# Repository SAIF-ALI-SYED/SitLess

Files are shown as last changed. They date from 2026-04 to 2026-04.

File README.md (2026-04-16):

# SitLess

**An AI-Driven Sedentary Monitoring System with a 3-DOF Robotic Arm**

SitLess is an AIoT system that detects prolonged sitting using an ESP32 microcontroller, ultrasonic sensor, and a trained Random Forest classifier. When sitting is detected for too long, alerts escalate — from a buzzer beep (30s) to a physical robotic arm tap (60s). A Streamlit dashboard provides real-time monitoring and manual controls.

> Built as a second-year individual project.

---

<p align="center">
  SitLess Demo
</p>

<p align="center">
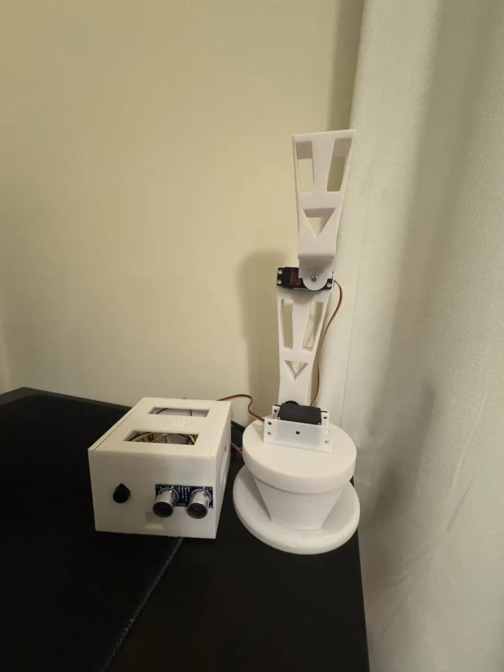
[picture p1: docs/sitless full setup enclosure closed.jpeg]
Full Setup
  
  &nbsp;&nbsp;
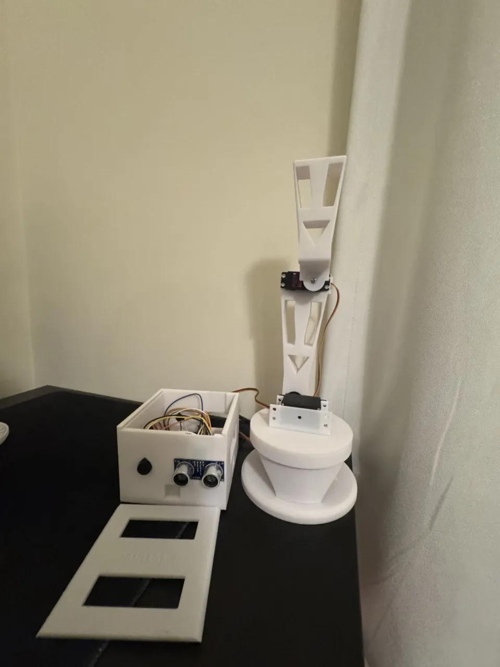
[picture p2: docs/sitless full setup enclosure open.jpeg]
Inside View
  
  &nbsp;&nbsp;
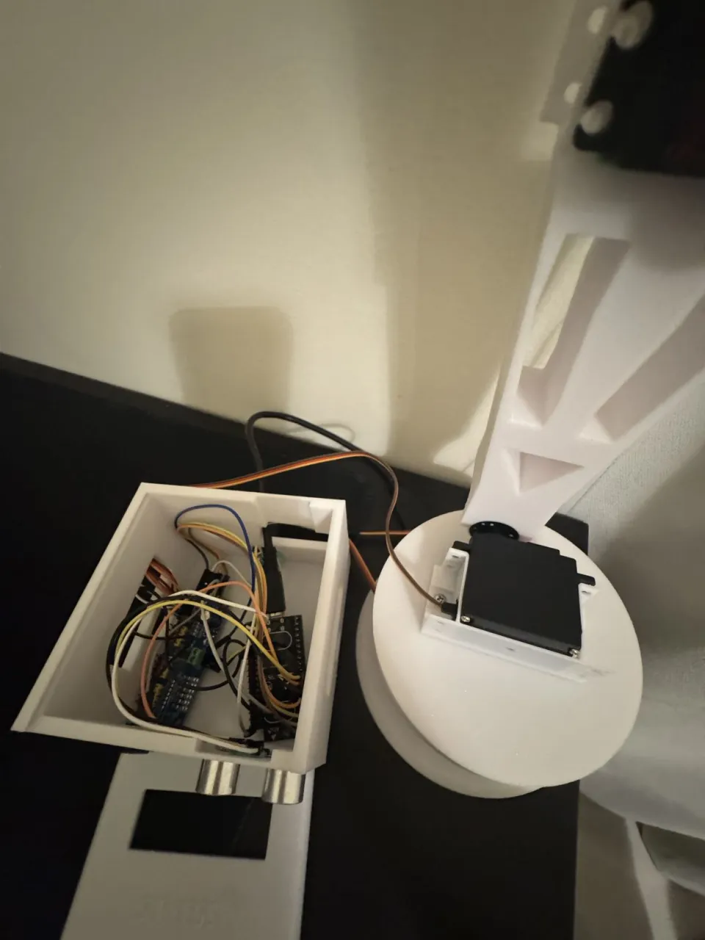
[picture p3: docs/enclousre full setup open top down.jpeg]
Top-Down
  
</p>

---

## How It Works

```
HC-SR04 Sensor → ESP32 → Serial → Python Backend → Random Forest → Alert System
                                                                    ├── Buzzer (30s)
                                                                    └── Robotic Arm Tap (60s)
```

1. The **ESP32** reads ultrasonic distance every 200ms and sends it over serial
2. The **Python backend** collects readings into sliding windows (10 samples, step 5) and extracts features
3. A **Random Forest classifier** predicts the activity state: `active`, `sedentary`, or `not present`
4. If sedentary for too long, **escalating alerts** trigger — first a buzzer beep, then a physical tap from the 3-DOF arm
5. A **Streamlit dashboard** shows real-time state, distance, inactivity timer, and provides manual controls

---

## Machine Learning

| Detail | Value |
|---|---|
| Model | Random Forest (100 estimators) |
| Test Accuracy | **85.1%** |
| Dataset | 1,473 samples → 234 feature windows |
| Window Size | 10 samples (step 5) ≈ 2 seconds |
| Classes | Active, Sedentary, Not Present |

### Features Extracted Per Window

| Feature | Description | Importance |
|---|---|---|
| `rate_of_change` | Mean absolute difference between consecutive readings | **34.5%** |
| `std_distance` | Standard deviation of distances | **26.8%** |
| `range_distance` | Max − Min distance in window | **22.6%** |
| `mean_distance` | Average distance | 16.1% |

The top features (rate of change and standard deviation) capture **movement variability** — the key signal distinguishing active vs sedentary behaviour.

---

## Hardware

| Component | Purpose |
|---|---|
| ESP-32D | Microcontroller |
| HC-SR04 | Ultrasonic distance sensor |
| PCA9685 | 16-channel PWM servo driver |
| 3× MG996R | Servo motors (base, shoulder, elbow) |
| Piezo buzzer | Audio alert |
| 5V 3A DC supply | Power |
| 3D-printed PLA enclosure | Housing (FreeCAD files included) |

**Total hardware cost: approximately 200 AED (~$55 USD)**

---

## Repository Structure

```
SitLess/
├── Sitless_Final_Arduino_Code.ino   # ESP32 firmware (Arduino IDE)
├── Python & CSV & Graphs/
│   ├── live_prediction.ipynb        # ML backend — serial + prediction + alerts
│   ├── dashboard.py                 # Streamlit web dashboard
│   ├── data_collection.ipynb        # Raw data collection from sensor
│   ├── data_cleaning.ipynb          # Cleaning & preprocessing
│   ├── extract_features.ipynb       # Sliding window feature extraction
│   ├── model_training.ipynb         # Model training & evaluation
│   ├── *.csv                        # Datasets (raw + processed)
│   └── *.png                        # Output charts & visualisations
├── FreeCAD files/                   # CAD files for enclosure & robotic arm
└── README.md
```

---

## Getting Started

### Prerequisites

- Python 3.8+
- Arduino IDE
- ESP32 board package installed in Arduino IDE

### Install Dependencies

```bash
pip install pyserial pandas numpy scikit-learn joblib streamlit matplotlib
```

### 1. Flash the ESP32

Open `Sitless_Final_Arduino_Code.ino` in Arduino IDE and upload to your ESP32 (connected on COM4 by default).

### 2. Start the ML Backend

```bash
# Open Jupyter and run:
jupyter notebook "Python & CSV & Graphs/live_prediction.ipynb"
```

### 3. Launch the Dashboard

```bash
# In a separate terminal:
streamlit run "Python & CSV & Graphs/dashboard.py"
```

The backend and dashboard communicate via shared JSON files (`state.json` and `commands.json`).

---

## Alert Escalation Logic

```
Sedentary detected → Timer starts
                     ├── 0–30s:  Monitoring (no alert)
                     ├── 30s:    Buzzer beep
                     └── 60s:    Robotic arm tap
                     
Active for 5s → Timer resets
```

---

## Custom 3-DOF Robotic Arm

The robotic arm was designed from scratch in FreeCAD and 3D-printed in PLA. It has three degrees of freedom — base rotation, shoulder lift, and elbow extension — driven by three MG996R servo motors through a PCA9685 PWM driver.

The arm's tap motion was tuned manually using incremental stepping to find reliable angles:

| Joint | Rest Position | Tap Position |
|---|---|---|
| Base | 180° | 40° |
| Shoulder | 90° | 150° |
| Elbow | 90° | 40° |

On a tap command, the servos move sequentially — base rotates, shoulder raises, elbow extends — then retract in reverse order. The motion is deliberate enough to get your attention without being aggressive.

The `FreeCAD files/` folder contains all the CAD models for both the arm and the sensor enclosure (which holds the HC-SR04 at the front with the ESP32 mounted inside).

---

## Future Improvements

- Multi-user data collection for better generalisation
- Bluetooth/Wi-Fi to replace USB serial
- Inverse kinematics to replace the current predefined angle movements with dynamic positioning
- Historical data logging and wellness trend tracking
- Additional sensors (PIR, second ultrasonic) for better accuracy
- On-device inference for privacy

---

## Built With

- **Hardware:** ESP32, HC-SR04, PCA9685, MG996R servos
- **ML:** scikit-learn (Random Forest), pandas, NumPy
- **Dashboard:** Streamlit
- **CAD:** FreeCAD
- **Firmware:** Arduino (C++)

---

## License

This project was developed for academic purposes. Feel free to use it as reference or inspiration for your own projects.

---

## Author

**Saif Ali Syed** — BEng (Honours) Computer Systems Engineering, Middlesex University Dubai  
[LinkedIn](https://www.linkedin.com/in/saif-ali-syed-a87aa534a/) <!-- Replace with your actual LinkedIn URL -->

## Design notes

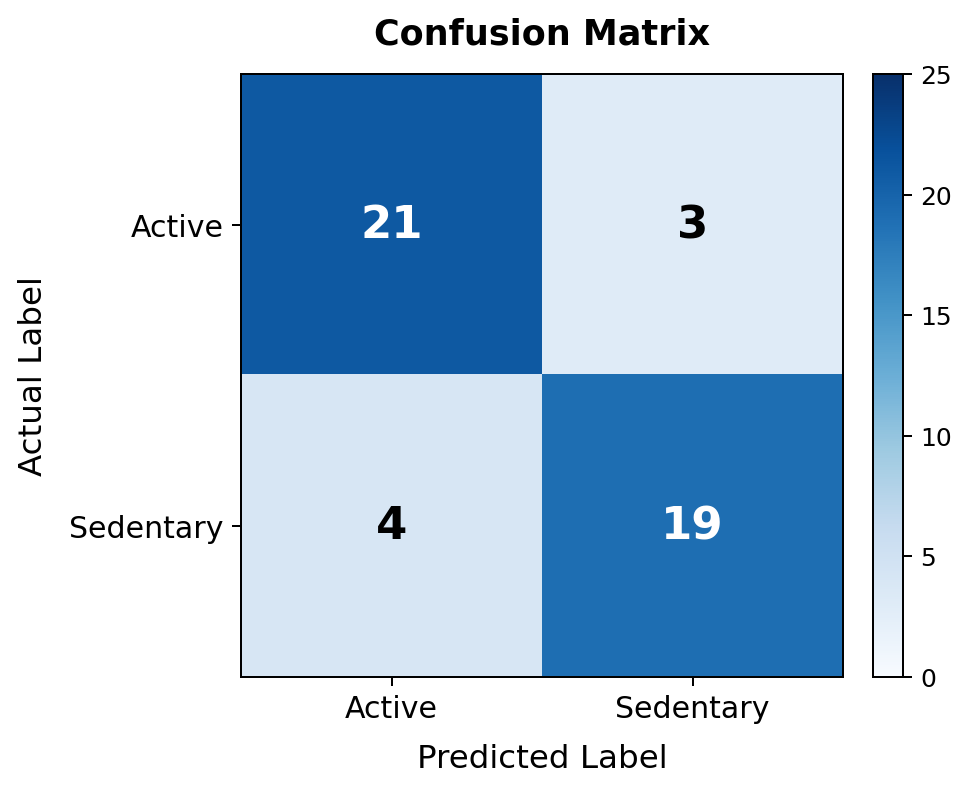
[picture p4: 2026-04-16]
SitLess Files/Python & CSV & Graphs/confusion_matrix.png

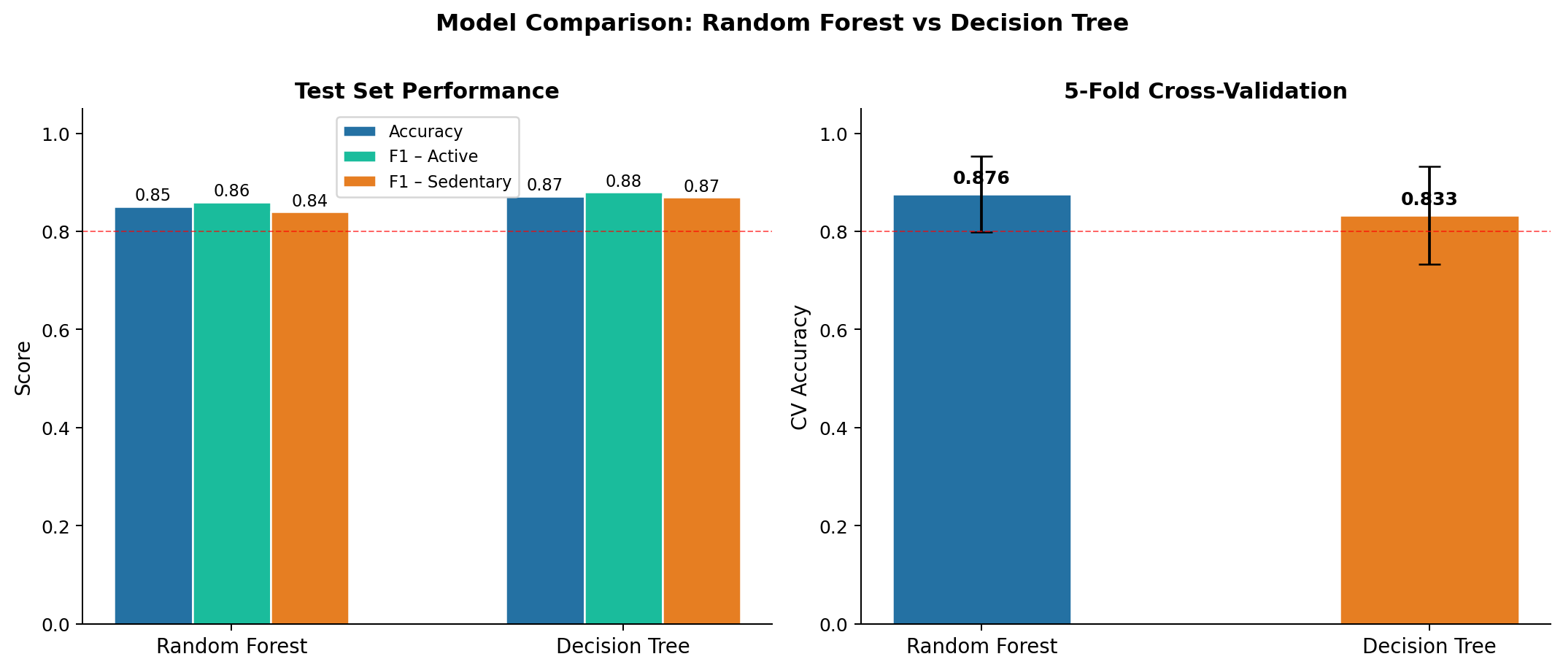
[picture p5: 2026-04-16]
SitLess Files/Python & CSV & Graphs/model_comparison.png

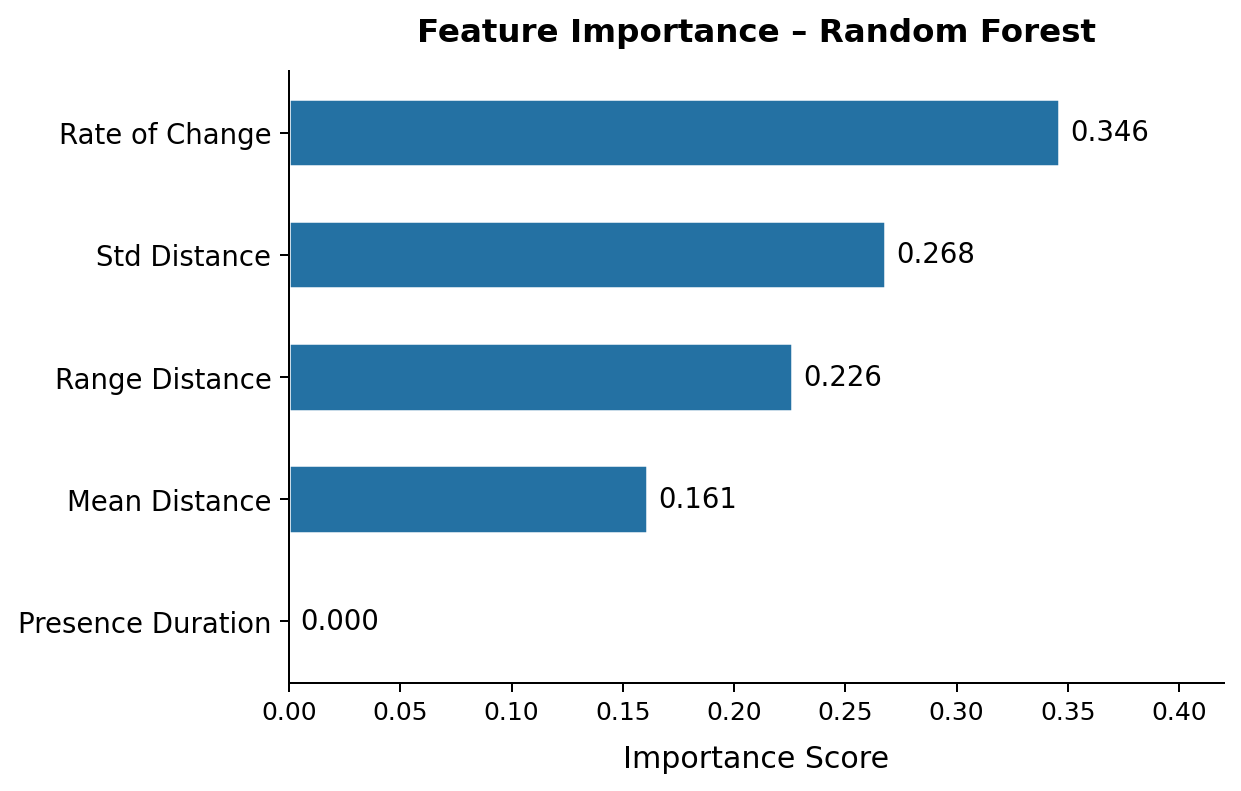
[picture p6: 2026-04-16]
SitLess Files/Python & CSV & Graphs/feature_importance.png

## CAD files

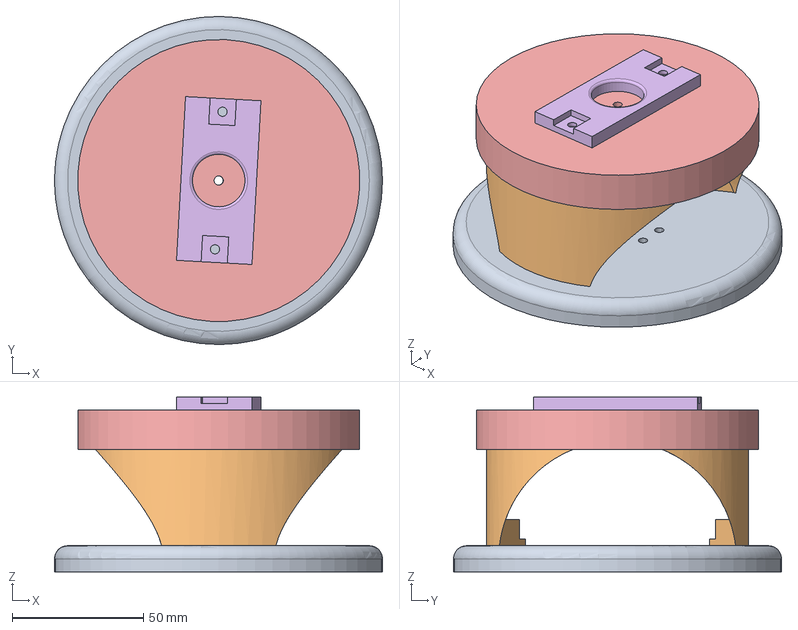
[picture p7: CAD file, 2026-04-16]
SitLess Files/FreeCAD files/SitLess FreeCad/3DOF arm/Main Assembly & Parts.FCStd
125.0 x 125.0 x 66.7 mm
base
turntable bearing
skeleton of bearing v2
bearing
top moving surface
top moving surface connector

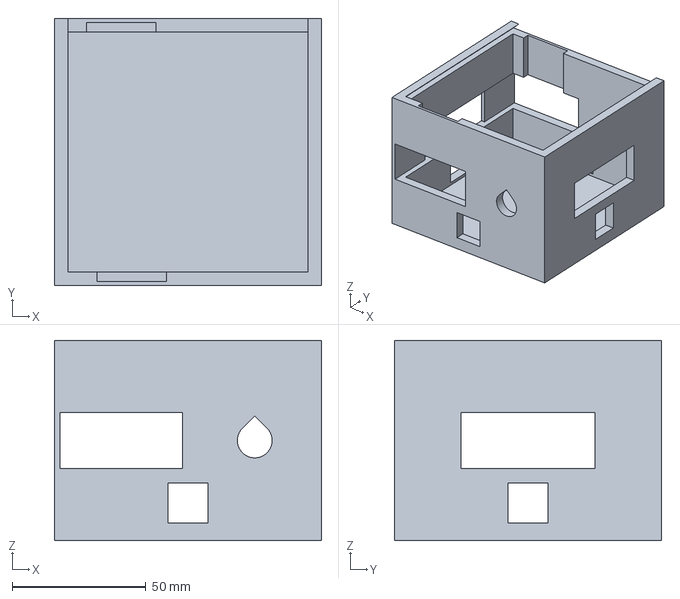
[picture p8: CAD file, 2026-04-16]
SitLess Files/FreeCAD files/SitLess FreeCad/case of sitless components-Assemblybox001.3mf
100.0 x 100.0 x 75.0 mm

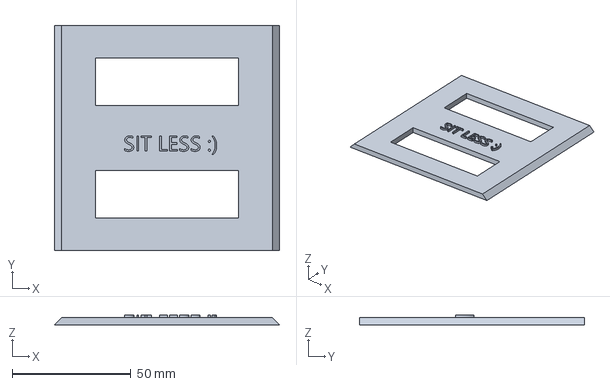
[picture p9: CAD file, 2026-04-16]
SitLess Files/FreeCAD files/SitLess FreeCad/case of sitless components-Assemblylid001.3mf
94.7 x 94.8 x 4.02 mm

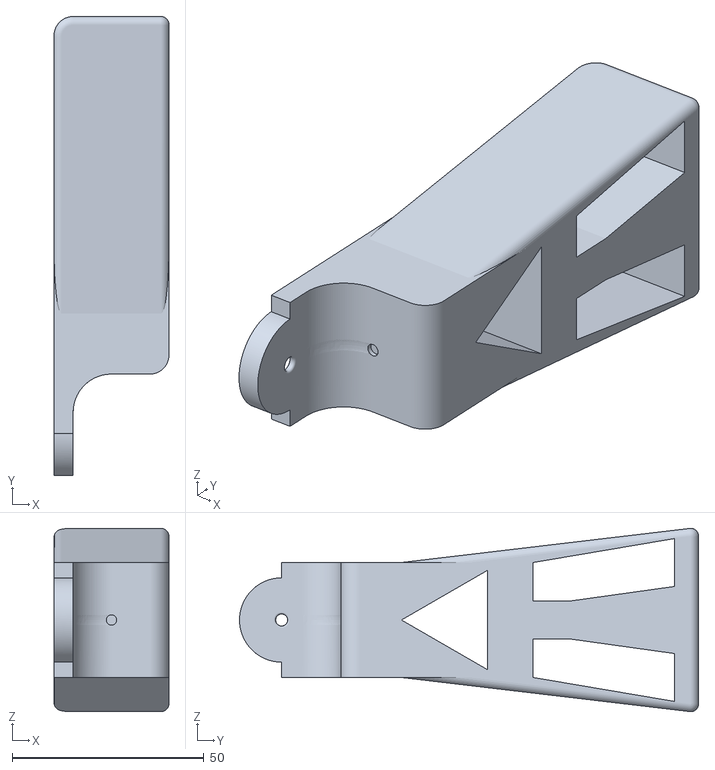
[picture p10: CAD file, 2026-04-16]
SitLess Files/FreeCAD files/SitLess FreeCad/3DOF arm/2nd arm_v3-Body.stl
30.0 x 119.8 x 47.8

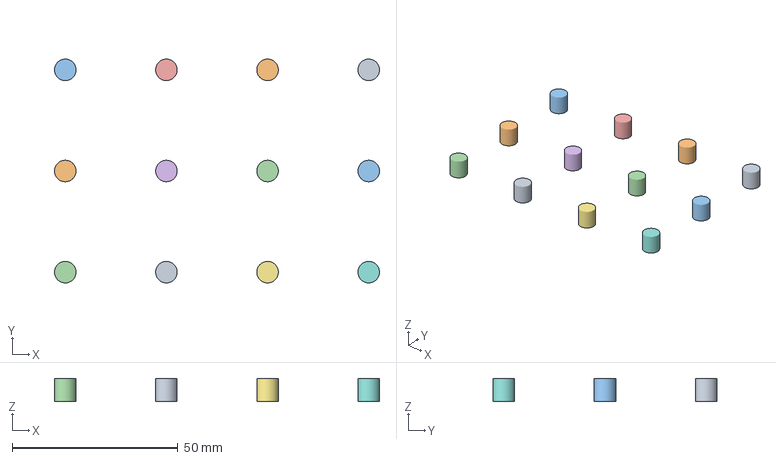
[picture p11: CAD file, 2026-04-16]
SitLess Files/FreeCAD files/SitLess FreeCad/3DOF arm/stl files/bearing v3.3mf
98.0 x 67.5 x 7.00 mm
bearing v3.stl x 12

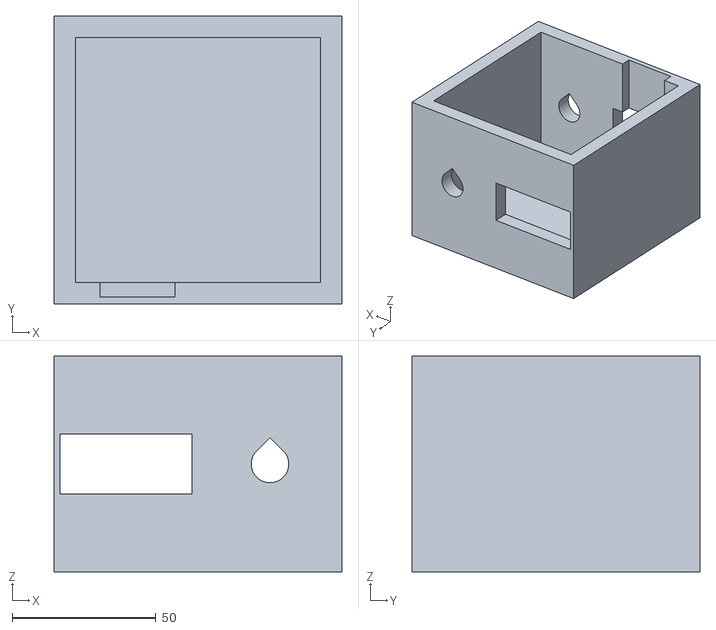
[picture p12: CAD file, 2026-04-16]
SitLess Files/FreeCAD files/SitLess FreeCad/case of sitless components-Body.stl
100.0 x 100.0 x 75.0

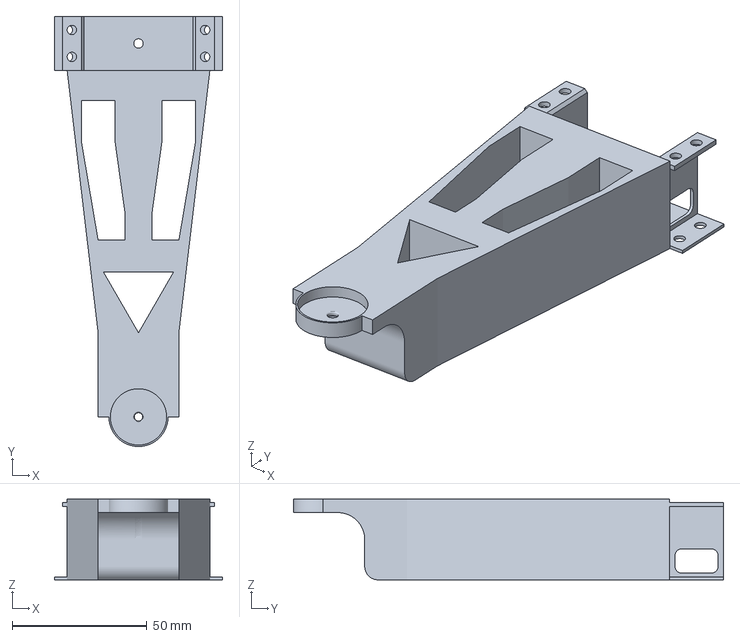
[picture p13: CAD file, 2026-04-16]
SitLess Files/FreeCAD files/SitLess FreeCad/3DOF arm/stl files/1st_arm_v4-Body.3mf
62.5 x 159.8 x 30.0 mm

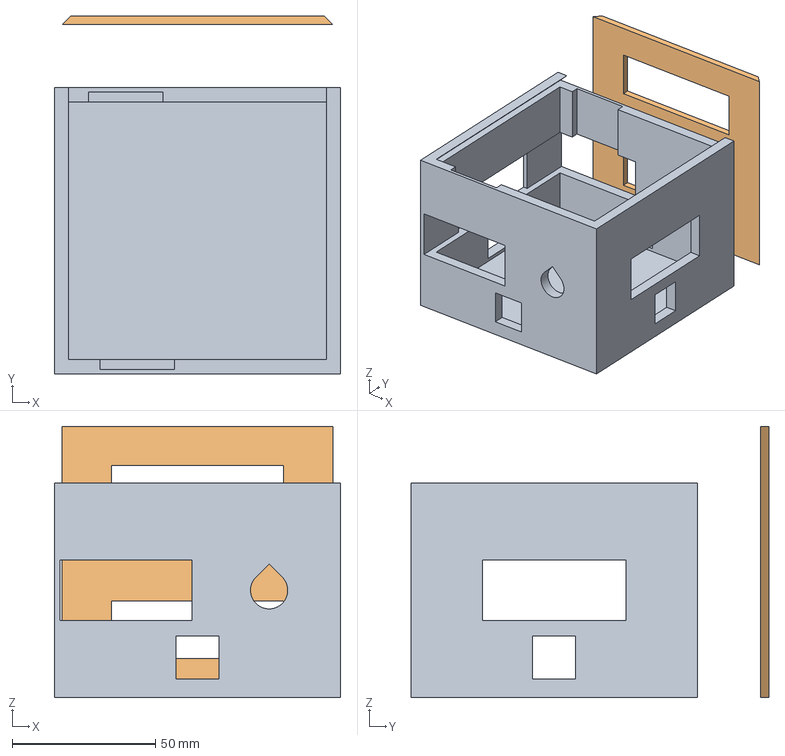
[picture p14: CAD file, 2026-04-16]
SitLess Files/FreeCAD files/SitLess FreeCad/case of sitless components.FCStd
100.0 x 125.0 x 94.8 mm
lid

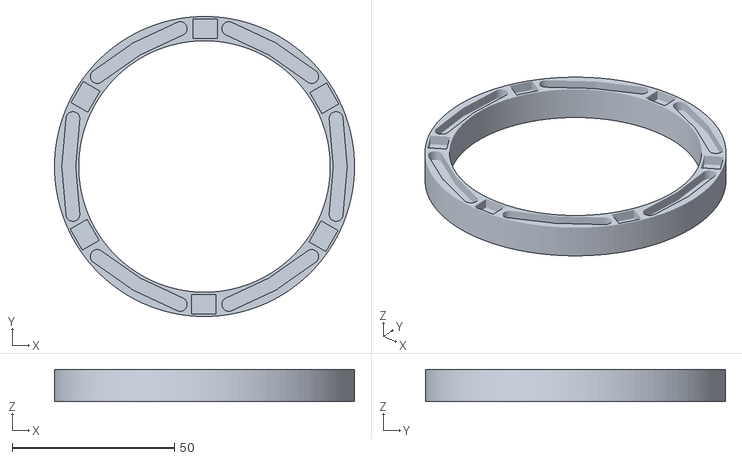
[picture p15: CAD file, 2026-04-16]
SitLess Files/FreeCAD files/SitLess FreeCad/3DOF arm/stl files/skeleton of turntable bearing v2.stl
92.5 x 92.5 x 10.0

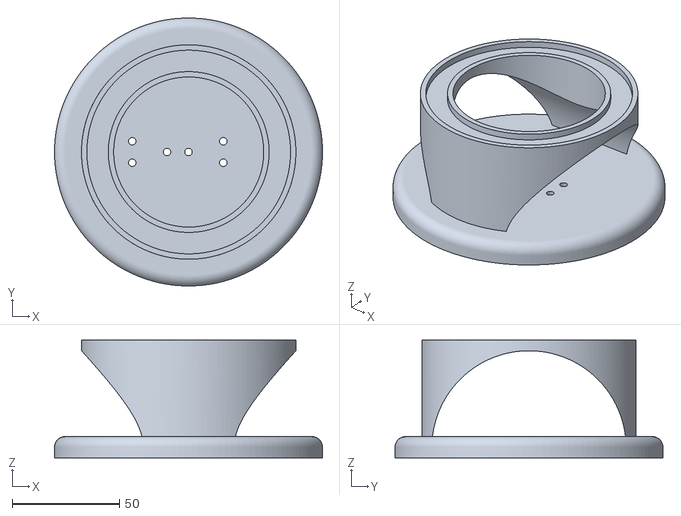
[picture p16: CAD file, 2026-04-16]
SitLess Files/FreeCAD files/SitLess FreeCad/3DOF arm/stl files/base and turntable v3 (even higher height).stl
125.0 x 125.0 x 55.0

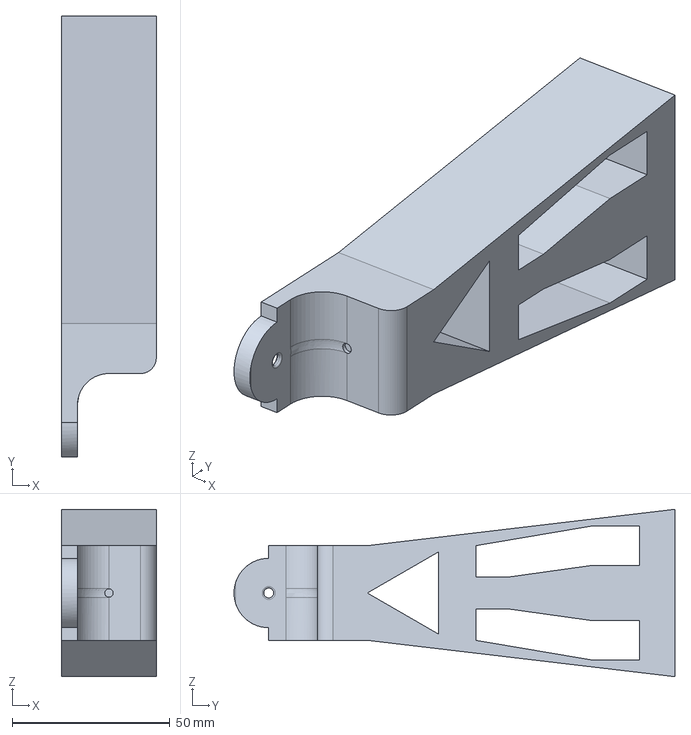
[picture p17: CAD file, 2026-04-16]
SitLess Files/FreeCAD files/SitLess FreeCad/3DOF arm/1st arm_v2.FCStd
30.0 x 139.8 x 53.0 mm

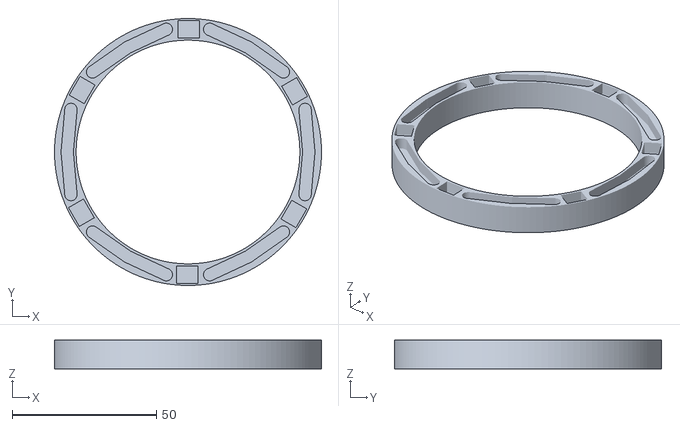
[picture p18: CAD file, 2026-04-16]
SitLess Files/FreeCAD files/SitLess FreeCad/3DOF arm/stl files/skeleton of turntable bearings.stl
92.5 x 92.5 x 10.0

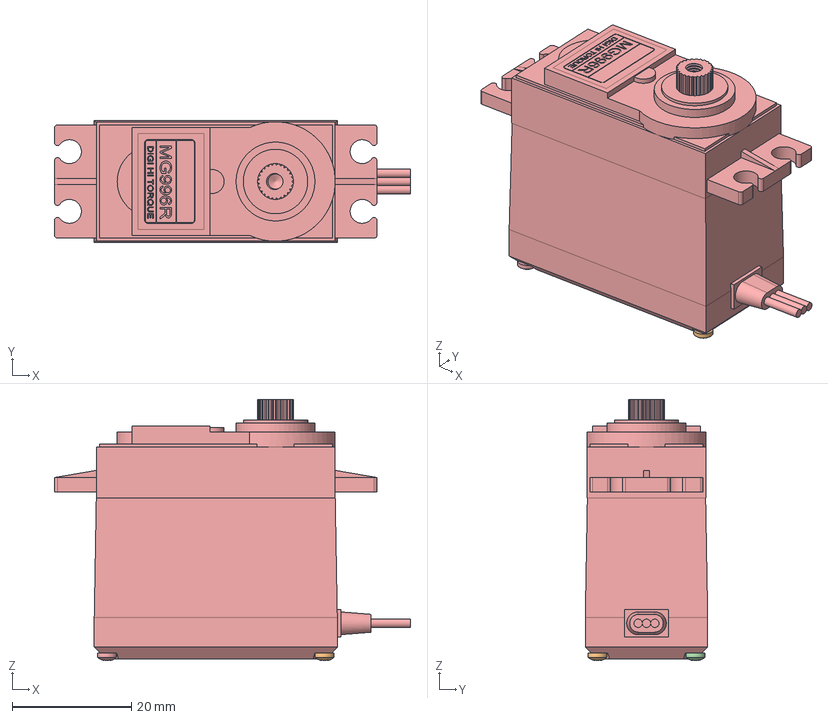
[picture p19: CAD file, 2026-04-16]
SitLess Files/FreeCAD files/SitLess FreeCad/mg996R_v2.FCStd
59.6 x 20.5 x 43.8 mm
M1.6x8-Screw
M1.6x8-Screw004
M1.6x8-Screw005
M1.6x8-Screw006

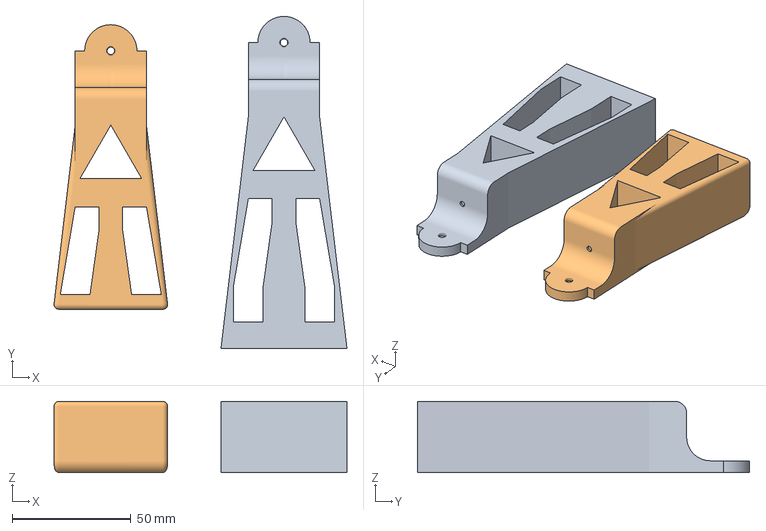
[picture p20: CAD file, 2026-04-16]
SitLess Files/FreeCAD files/SitLess FreeCad/3DOF arm/1st arm_v3-Body.3mf
123.3 x 139.8 x 30.0 mm
1st arm_v3-Body.stl
2nd arm_v3-Body.stl

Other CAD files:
SitLess Files/FreeCAD files/SitLess FreeCad/3DOF arm/test_assembly.FCStd
SitLess Files/FreeCAD files/SitLess FreeCad/3DOF arm/2nd arm_v2.FCStd
SitLess Files/FreeCAD files/SitLess FreeCad/3DOF arm/stl files/base & turntable v2 (higher height).3mf
SitLess Files/FreeCAD files/SitLess FreeCad/mg996r round arm.FCStd
SitLess Files/FreeCAD files/SitLess FreeCad/3DOF arm/1st arm_v3-Body.stl
SitLess Files/FreeCAD files/SitLess FreeCad/3DOF arm/Unnamed backup.FCStd
SitLess Files/FreeCAD files/SitLess FreeCad/3DOF arm/stl files/1st arm v2 not finished test.stl
SitLess Files/FreeCAD files/SitLess FreeCad/3DOF arm/stl files/1st arm v2 with mg996r case attached.3mf
SitLess Files/FreeCAD files/SitLess FreeCad/3DOF arm/stl files/1st arm v3 with mg996r case attached & 2nd arm v3.3mf
SitLess Files/FreeCAD files/SitLess FreeCad/3DOF arm/stl files/1st arm v3.stl
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

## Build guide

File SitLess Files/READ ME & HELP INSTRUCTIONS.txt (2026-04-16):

# SitLess
### AI-Driven Sedentary Monitoring System with a 3-DOF Robotic Arm

An AIoT system that detects prolonged sitting using an ESP32 ultrasonic 
sensor and a trained Random Forest classifier. When sitting is detected 
for too long, alerts escalate from a buzzer beep (30s) to a physical 
robotic arm tap (60s). A Streamlit dashboard provides real-time monitoring 
and manual controls.

## Folder Structure
| Folder/File | Description |
|---|---|
| `Sitless_Final_Arduino_Code.ino` | ESP32 firmware (Arduino IDE) |
| `Python & CSV & Graphs/` | Jupyter notebooks, datasets, output charts |
| `FreeCAD files/` | CAD files for enclosure and robotic arm |

## How to Run
1. Flash `Sitless_Final_Arduino_Code.ino` to the ESP32 via Arduino IDE
2. Open Jupyter and navigate to `Python & CSV & Graphs/`
3. Run `live_prediction.ipynb` to start the ML backend (ESP32 on COM4)
4. In a separate terminal: `streamlit run dashboard.py`

## Install Dependencies
pip install pyserial pandas numpy scikit-learn joblib streamlit

## Hardware
- ESP-32D microcontroller
- HC-SR04 ultrasonic distance sensor
- PCA9685 16-channel PWM servo driver
- 3x MG996R servo motors (base, shoulder, elbow)
- Piezo buzzer
- 5V 3A DC power supply
- 3D-printed PLA enclosure (FreeCAD files included)

## ML Results
- Model: Random Forest (100 estimators)
- Test Accuracy: 85.1%
- Top features: rate of change, standard deviation

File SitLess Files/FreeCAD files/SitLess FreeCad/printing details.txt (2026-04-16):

1st arm & 2nd arm v2 with mgg96r case attached to both of them - 3h51m (90.47g total, 83.06g model)
skeleton of turntable bearing & turntable bearing with bearings & case attached piece - 1h41m (51.72g)
base and turntable attached - 3h55m (98.15g total, 87.84g model)

total filament = 240.34g
total model filament = 222.62g

total time = 567m or 9.45h

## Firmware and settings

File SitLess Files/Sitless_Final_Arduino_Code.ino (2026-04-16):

#include <Wire.h>
#include <Adafruit_PWMServoDriver.h>
Adafruit_PWMServoDriver pwm(0x40);

// --- servo settings ---
#define SERVO_FREQ 60
#define SERVOMIN 210
#define SERVOMAX 500
#define S1_CHANNEL 0  // base servo (rotates left/right)
#define S2_CHANNEL 1  // shoulder servo (raises the arm)
#define S3_CHANNEL 2  // elbow servo (does the tapping)

// how fast and smooth the arm moves
#define STEP_DELAY 10
#define STEP_SIZE 2

// arm starts here and returns here after each action
int s1Angle = 180;
int s2Angle = 90;
int s3Angle = 90;
bool stopMotion = false;

// target angles for each servo during a tap
#define S1_TAP_TARGET 40
#define S2_TAP_TARGET 150
#define S3_TAP_TARGET 40

// ultrasonic sensor pins
#define TRIG_PIN 18
#define ECHO_PIN 19
unsigned long lastUltrasonicRead = 0;
const unsigned long ultrasonicInterval = 200;

// buzzer pin
#define BUZZER_PIN 23

// convert an angle (0-180) into a PWM pulse value
uint16_t angleToPulse(int angle) {
  angle = constrain(angle, 0, 180);
  return map(angle, 0, 180, SERVOMIN, SERVOMAX);
}

// move a servo to a given angle
void setServo(uint8_t ch, int angle) {
  angle = constrain(angle, 0, 180);
  pwm.setPWM(ch, 0, angleToPulse(angle));
}

// slowly step a servo from its current angle to the target angle
void moveServoSmooth(uint8_t channel, int &currentAngle, int targetAngle) {
  targetAngle = constrain(targetAngle, 0, 180);
  while (currentAngle != targetAngle && !stopMotion) {
    if (currentAngle < targetAngle) currentAngle = min(currentAngle + STEP_SIZE, targetAngle);
    else currentAngle = max(currentAngle - STEP_SIZE, targetAngle);
    setServo(channel, currentAngle);
    delay(STEP_DELAY);
  }
}

// bring the arm back to its resting position (elbow first, then shoulder, then base)
void goRest() {
  stopMotion = false;
  moveServoSmooth(S3_CHANNEL, s3Angle, 90);
  delay(400);
  moveServoSmooth(S2_CHANNEL, s2Angle, 90);
  delay(500);
  moveServoSmooth(S1_CHANNEL, s1Angle, 180);
  delay(400);
}

// tap sequence: base rotates, shoulder raises, elbow extends, then arm returns
void performTap(int times = 1) {
  stopMotion = false;
  for (int i = 0; i < times && !stopMotion; i++) {
    moveServoSmooth(S1_CHANNEL, s1Angle, S1_TAP_TARGET);
    delay(300);
    if (stopMotion) break;
    moveServoSmooth(S2_CHANNEL, s2Angle, S2_TAP_TARGET);
    delay(300);
    if (stopMotion) break;
    moveServoSmooth(S3_CHANNEL, s3Angle, S3_TAP_TARGET);
    delay(300);
    if (stopMotion) break;
    goRest();
    delay(300);
  }
}

// fire the ultrasonic sensor and return the distance in cm
long readUltrasonicCM() {
  digitalWrite(TRIG_PIN, LOW); delayMicroseconds(2);
  digitalWrite(TRIG_PIN, HIGH); delayMicroseconds(10);
  digitalWrite(TRIG_PIN, LOW);
  long duration = pulseIn(ECHO_PIN, HIGH, 30000);
  if (duration == 0) return -1;
  return duration / 58;
}

// beep the buzzer twice to alert the user
void beepNotify() {
  digitalWrite(BUZZER_PIN, HIGH); delay(60);
  digitalWrite(BUZZER_PIN, LOW);  delay(40);
  digitalWrite(BUZZER_PIN, HIGH); delay(100);
  digitalWrite(BUZZER_PIN, LOW);
}

// initial setup: serial, I2C, pins, and move arm to rest position
void setup() {
  Serial.begin(115200);
  Wire.begin();
  pinMode(TRIG_PIN, OUTPUT);
  pinMode(ECHO_PIN, INPUT);
  pinMode(BUZZER_PIN, OUTPUT);
  digitalWrite(BUZZER_PIN, LOW);
  pwm.begin();
  pwm.setPWMFreq(SERVO_FREQ);
  setServo(S1_CHANNEL, s1Angle);
  setServo(S2_CHANNEL, s2Angle);
  setServo(S3_CHANNEL, s3Angle);
  Serial.println("=== SitLess 3-DOF Ready ===");
  Serial.println("Commands: TAP | REST | BEEP | STOP");
}

// main loop: send distance readings and listen for commands
void loop() {
  if (millis() - lastUltrasonicRead >= ultrasonicInterval) {
    lastUltrasonicRead = millis();
    Serial.print("DIST:");
    Serial.println(readUltrasonicCM());
  }
  if (Serial.available()) {
    String cmd = Serial.readStringUntil('\n');
    cmd.trim(); cmd.toUpperCase();
    if (cmd == "TAP") { Serial.println("TAP"); performTap(1); }
    else if (cmd == "REST") { Serial.println("REST"); goRest(); }
    else if (cmd == "BEEP") { Serial.println("BEEP"); beepNotify(); }
    else if (cmd == "STOP") { Serial.println("STOP"); stopMotion = true; digitalWrite(BUZZER_PIN, LOW); }
  }
}
